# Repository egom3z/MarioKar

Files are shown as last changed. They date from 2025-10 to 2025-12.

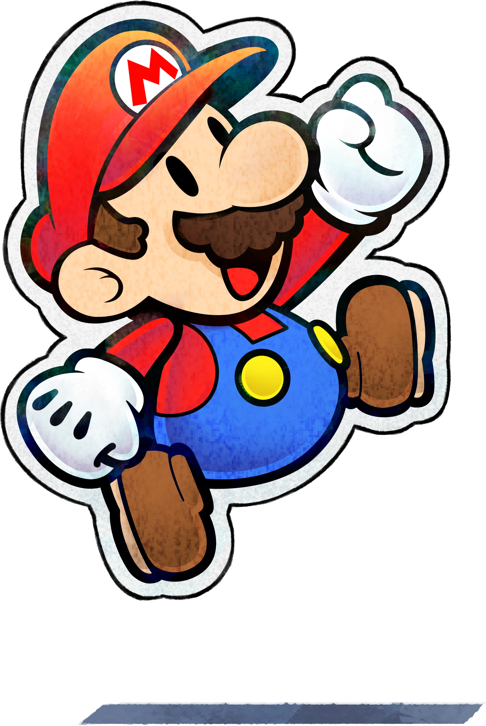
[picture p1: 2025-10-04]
Hardware/Kar_PCB_JLC/mascot.webp

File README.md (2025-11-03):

# MarioKar

## Development Setup

### Beginning Docker Container
#### **For Windows**
Before starting the docker container, the .devcontainer.json file requires that the USB device is connected the Linux distribution running on WSL 2. This will enable us to flash the ESP32 in the container. 

#### Connect USB Device
Prerequisites (can also refer to https://learn.microsoft.com/en-us/windows/wsl/connect-usb): 
* WSL is installed 
* Install USBIPD-WIN

Instructions to be done every session: 
1. Connect USB device to computer and list device in Windows Powershell in *administrator* mode: \
`usbipd list`

2. Run the command below with the bus ID of the ESP32 device: \
`usbipd bind --busid 4-4`

3. Attach the USB device: \
`usbipd attach --wsl --busid <busid>`

4. Open the **MarioKar** repo and `ctrl+shift+P` and type `Dev Containers: Rebuild and Reopen in Container`

### Build and Flash ESP32S3
If the ESP-IDF extension doesn't work when building or flashing, open a terminal within VSCode and follow the instructions below. 

1. `source /opt/esp/idf/export.sh`
2. Navigate to the project directory, and configure the target by running \
`idf.py set-target esp32s3`
3. Build the project with \
`idf.py build`
4. Flash the project to the board with \
`idf.py flash`

* After flashing, you can open the serial monitor \
`idf.py monitor`\
and close serial monitor with \
`ctrl+]`

### Alternative Setup (macOS/Linux)
```bash
# Install prerequisites
brew install cmake ninja dfu-util

# Install ESP-IDF tools
brew install espressif/idf/esp-idf-tools

# Setup ESP-IDF environment
/opt/esp/idf/install.sh
source /opt/esp/idf/export.sh

# Create and build project
cd /workspaces/MarioKar
idf.py create-project hello_world
cd hello_world
idf.py set-target esp32s3      # or esp32s3/esp32c3/etc if that's your chip
idf.py build
idf.py flash
```

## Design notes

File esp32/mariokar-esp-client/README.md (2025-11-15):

# MarioKar ESP32 BLE Client with IMU Control

ESP32-S3 BLE GATT client that reads IMU orientation and transmits servo PWM values (1000-2000 µs) to STM32WB over Bluetooth.

## Features

- ✅ **Multi-Sensor Support**: Choose between MPU6050 (I2C) or ICM-20948 (SPI)
- ✅ **Servo Mapping**: Converts roll angle (-90° to +90°) to PWM (1000-2000 µs)
- ✅ **BLE Transmission**: Sends 2-byte PWM values at 50ms intervals
- ✅ **Auto-Calibration**: Gyroscope bias calibration on startup
- ✅ **Connection Management**: Auto-scan, connect, and retry
- ✅ **Madgwick AHRS**: Sensor fusion for accurate orientation

## Supported IMU Sensors

### MPU6050 (Default - I2C)
- **Axes**: 6-axis (accelerometer + gyroscope)
- **Interface**: I2C
- **Pins (XIAO ESP32-S3)**:
  - SCL: GPIO 6
  - SDA: GPIO 5
- **Features**: 
  - ±4g accelerometer range
  - ±500°/s gyroscope range
  - No magnetometer (yaw will drift without external reference)
- **When to use**: Budget-friendly, easier wiring, sufficient for roll/pitch control

### ICM-20948 (SPI)
- **Axes**: 9-axis (accelerometer + gyroscope + magnetometer)
- **Interface**: SPI
- **Pins (XIAO ESP32-S3)**:
  - MISO: GPIO 8
  - MOSI: GPIO 9
  - SCLK: GPIO 7
  - CS: GPIO 44
- **Features**:
  - ±4g accelerometer range
  - ±500°/s gyroscope range
  - AK09916 magnetometer for absolute heading
- **When to use**: Need accurate yaw/heading, willing to pay premium

## Selecting IMU Sensor

Edit `main/sensor.h` and change the sensor type:

```c
// For MPU6050 (I2C)
#define IMU_SENSOR_TYPE     IMU_TYPE_MPU6050

// OR for ICM-20948 (SPI)
#define IMU_SENSOR_TYPE     IMU_TYPE_ICM20948
```

The build system will automatically compile only the relevant sensor driver.

## Hardware Connections

### Option 1: MPU6050 (I2C) - Default
```
MPU6050          XIAO ESP32-S3
  VCC    <-->    3.3V
  GND    <-->    GND
  SCL    <-->    GPIO 6
  SDA    <-->    GPIO 5
```

### Option 2: ICM-20948 (SPI)
```
ICM-20948        XIAO ESP32-S3
  VCC    <-->    3.3V
  GND    <-->    GND
  MISO   <-->    GPIO 8
  MOSI   <-->    GPIO 9
  SCLK   <-->    GPIO 7
  CS     <-->    GPIO 44
```

## Software Architecture

```
┌─────────────────────────────────────────────────────┐
│              app_main()                             │
│  ┌───────────────────┐  ┌──────────────────────┐  │
│  │  imu_reader_task  │  │    ble_tx_task       │  │
│  │  (100 Hz)         │  │    (20 Hz)           │  │
│  └─────────┬─────────┘  └──────────┬───────────┘  │
│            │                        │              │
│            ▼                        ▼              │
│  ┌─────────────────┐      ┌────────────────┐     │
│  │  Sensor Driver  │      │  BLE TX Buffer  │     │
│  │  (MPU/ICM)      │─────▶│  (s_latest_pwm) │     │
│  └─────────────────┘      └────────────────┘     │
│            │                        │              │
│            ▼                        ▼              │
│  ┌─────────────────┐      ┌────────────────┐     │
│  │ Madgwick Filter │      │  GATT Client   │     │
│  │ (6/9-DOF AHRS)  │      │                │     │
│  └─────────────────┘      └────────┬───────┘     │
│            │                        │              │
│            ▼                        ▼              │
│  ┌─────────────────┐      ┌────────────────┐     │
│  │ Euler Angles    │      │   STM32WB      │     │
│  │ (Roll/Pitch/Yaw)│      │   (BLE Server) │     │
│  └─────────────────┘      └────────────────┘     │
└─────────────────────────────────────────────────────┘
```

## Building and Flashing

### Prerequisites
```bash
# Install ESP-IDF v5.x
cd /opt/esp/idf
./install.sh
source export.sh
```

### Build
```bash
cd esp32/mariokar-esp-client
idf.py set-target esp32s3
idf.py build
```

### Flash
```bash
idf.py flash monitor
```

### Expected Output
```
I (1234) MPU6050: Initializing MPU6050 IMU
I (1245) MPU6050: MPU6050 initialized successfully (I2C mode)
I (1250) MPU6050: Calibrating gyroscope... keep device stationary!
I (1255) MPU6050: Progress: 0%
...
I (3456) MPU6050: Calibration complete (1000 samples)
I (3460) MPU6050: Gyro offsets: X=-0.234 Y=0.123 Z=-0.056 deg/s
I (3465) GATTC_CLEAN: IMU ready, starting orientation tracking
I (3470) GATTC_CLEAN: BLE TX task started (interval 50 ms)
I (4567) GATTC_CLEAN: Found target device MyCST
I (5678) GATTC_CLEAN: P2P Service found: start=0x000c end=0x0010
I (5890) GATTC_CLEAN: LED value handle 0x000d
I (6123) GATTC_CLEAN: SWITCH decl handle 0x000f
I (6234) GATTC_CLEAN: Notifications enabled.
I (6345) GATTC_CLEAN: BLE TX: PWM=1500 µs [0xDC 0x05]
I (7456) GATTC_CLEAN: IMU: Roll=-15.3° -> PWM=1415 µs
```

## Calibration

**Important**: Keep the device **completely stationary** during the ~2 second gyroscope calibration on startup. This measures and removes gyroscope bias for accurate orientation tracking.

## Steering Control Mapping

The system uses **ROLL** angle for steering:

| Roll Angle | Servo PWM | Steering Direction |
|---|---|---|
| -90° | 1000 µs | Full Left |
| -45° | 1250 µs | Half Left |
| 0° | 1500 µs | Center/Straight |
| +45° | 1750 µs | Half Right |
| +90° | 2000 µs | Full Right |

## Code Structure

```
main/
├── main.c              # BLE client, IMU reader, TX tasks
├── sensor.h            # Common IMU API & sensor selection
├── sensor.c            # ICM-20948 driver (SPI, 9-axis)
├── sensor_mpu6050.c    # MPU6050 driver (I2C, 6-axis)
├── idf_component.yml   # MPU6050 component dependency
└── CMakeLists.txt      # Build configuration
```

## Sensor Fusion Details

Both sensors use the **Madgwick AHRS algorithm** for sensor fusion:

### MPU6050 (6-DOF Mode)
- Fuses accelerometer + gyroscope data
- No magnetometer → **yaw will drift** over time
- Excellent for roll and pitch (used for steering)
- Sample rate: 100 Hz
- Filter beta: 0.1 (tunable for response vs smoothness)

### ICM-20948 (9-DOF Mode)
- Fuses accelerometer + gyroscope + magnetometer
- Magnetometer provides absolute heading reference
- Yaw is stable and doesn't drift
- Sample rate: 100 Hz
- Filter beta: 0.1

## Troubleshooting

### IMU not detected
**MPU6050:**
- Check I2C connections (SCL on GPIO 6, SDA on GPIO 5)
- Verify 3.3V power supply
- Try adding external 4.7kΩ pull-up resistors on SCL/SDA

**ICM-20948:**
- Check SPI connections (see pinout above)
- Verify CS line is connected to GPIO 44
- Ensure 3.3V power (not 5V)

### Orientation drifts
- Ensure device was **stationary** during calibration
- For MPU6050: Yaw drift is normal (no magnetometer)
- Recalibrate by restarting the device
- Check for magnetic interference if using ICM-20948

### BLE connection fails
- Verify STM32WB is advertising as "MyCST"
- Check that P2P service UUID matches
- Monitor with `idf.py monitor` for connection logs
- Try power cycling both devices

### Roll angle reversed
- Swap sign in `angle_to_servo_pwm()` function in `main.c`
- Or physically mount IMU rotated 180°

## Customization

### Change steering axis
In `main.c`, line ~412:
```c
// Use PITCH instead of ROLL
s_latest_pwm = angle_to_servo_pwm(orientation.pitch);

// Or use YAW (only stable with ICM-20948)
s_latest_pwm = angle_to_servo_pwm(orientation.yaw);
```

### Adjust transmission rate
In `main.c`, line ~34:
```c
#define BLE_TX_INTERVAL_MS      50  // Change to 20 for 50Hz, 100 for 10Hz
```

### Tune sensor fusion
In `sensor_mpu6050.c` or `sensor.c`, adjust filter parameters:
```c
madgwick_init(&g_filter, 100.0f, 0.1f);
//                        ^       ^
//                        |       beta (filter gain)
//                        sample rate (Hz)
```

## Performance Metrics

| Metric | MPU6050  | ICM-20948 |
|---|---|---|
| Update Rate | 100 Hz | 100 Hz |
| BLE TX Rate | 20 Hz | 20 Hz |
| Roll/Pitch Accuracy | ±2° | ±2° |
| Yaw Accuracy | Drifts | ±5° |
| Calibration Time | ~2 sec | ~2 sec |
| Latency (IMU→BLE) | ~60 ms | ~60 ms |

## License

See project root LICENSE file.

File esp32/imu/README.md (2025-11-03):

# ICM-20948 IMU Driver

Clean, production-quality driver for the ICM-20948 9-axis IMU with SPI interface.

## Features

- ✅ **SPI Communication** - 4 MHz SPI interface with proper register banking
- ✅ **9-Axis Fusion** - Accelerometer, gyroscope, and magnetometer
- ✅ **Madgwick AHRS** - Quaternion-based sensor fusion for accurate orientation
- ✅ **Auto Calibration** - Gyroscope bias calibration on startup
- ✅ **I2C Master Mode** - Automatic magnetometer reading via I2C passthrough
- ✅ **Clean API** - Simple, well-documented interface

## Hardware Configuration

**XIAO ESP32S3 Pin Mapping:**
- MISO: GPIO 8
- MOSI: GPIO 9
- SCLK: GPIO 7
- CS: GPIO 44

## Sensor Configuration

- **Gyroscope**: ±500 dps, DLPF enabled (51.2 Hz bandwidth)
- **Accelerometer**: ±4g, DLPF enabled (50.4 Hz bandwidth)
- **Magnetometer**: Continuous 100 Hz mode via I2C master
- **Update Rate**: 100 Hz (10ms loop)

## API Usage

### Initialization

```c
#include "sensor.h"

void app_main(void) {
    if (imu_init() == ESP_OK) {
        ESP_LOGI("MAIN", "IMU ready");
        xTaskCreate(imu_task, "imu_task", 4096, NULL, 5, NULL);
    }
}
```

### Reading Sensors

```c
imu_data_t data;
if (imu_read_sensors(&data) == ESP_OK) {
    // data.accel_x, accel_y, accel_z (in g)
    // data.gyro_x, gyro_y, gyro_z (in deg/s)
    // data.mag_x, mag_y, mag_z (in uT)
    // data.mag_valid (magnetometer data ready flag)
}
```

### Getting Orientation

```c
imu_orientation_t orientation;
imu_get_orientation(&orientation);
// orientation.roll, pitch, yaw (in degrees)
```

### Manual Sensor Fusion

```c
float dt = 0.01f;  // 10ms
imu_update_fusion(&data, dt);
```

## Expected Behavior

### At Rest (Device Stationary)
- **Accelerometer magnitude**: ~1.0g (±0.1)
- **Gyroscope**: Near 0 deg/s after calibration
- **Roll/Pitch**: Near 0° if device is level
- **Yaw**: Arbitrary value aligned with magnetic north

### During Motion
- **Roll**: ±180° rotation around X-axis
- **Pitch**: ±90° rotation around Y-axis (gimbal lock at ±90°)
- **Yaw**: ±180° rotation around Z-axis (heading)

## Implementation Details

### Register Banking
The ICM-20948 uses register banks (0-3). The driver automatically tracks and switches banks as needed.

### Magnetometer Access
The AK09916 magnetometer is accessed via I2C master mode in the ICM-20948. The driver sets up continuous reading so magnetometer data appears in the external sensor data registers.

### Madgwick Filter
- Beta gain: 0.1 (tunable for responsiveness vs. stability)
- Uses fast inverse square root for efficiency
- Full 9-axis fusion with magnetometer correction

### Calibration
Gyroscope bias is measured on startup (1000 samples while stationary). The bias is automatically subtracted from all gyro readings.

## Build and Flash

```bash
cd /Users/enriquegomez/CMU/Fall-2025/18-500/MarioKar/esp32/imu
idf.py build
idf.py flash monitor
```

## Troubleshooting

### "Magnetometer not detected"
- Check I2C connections on the ICM-20948 board
- Verify magnetometer is powered
- Some breakout boards have magnetometer on a separate chip

### "Accel magnitude outside range"
- Check sensor orientation
- Verify ACCEL_CONFIG register (should be 0x13 for ±4g)
- Ensure device is stable during initialization

### Roll/Pitch/Yaw drifting
- Ensure gyroscope calibration completes successfully
- Keep device stationary during calibration
- Check magnetometer readings (mag_valid should be true)
- Increase calibration samples if needed

### SPI communication fails
- Verify GPIO pin assignments match your board
- Check SPI mode (should be mode 0)
- Ensure CS line is correctly connected

## Code Structure

```
sensor.h        - Public API and data structures
sensor.c        - Complete driver implementation
  ├── SPI layer (select_bank, read/write registers)
  ├── Magnetometer I2C master functions
  ├── Madgwick AHRS filter
  ├── Sensor reading functions
  └── Main IMU task with calibration
imu.c          - Application entry point
```

## Performance

- **CPU Usage**: ~2% on ESP32S3 @ 240MHz
- **RAM Usage**: <1KB static, ~2KB stack per task
- **Update Rate**: 100 Hz
- **Latency**: <2ms from sensor read to orientation output

## License

Part of MarioKar project - CMU 18-500 Fall 2025

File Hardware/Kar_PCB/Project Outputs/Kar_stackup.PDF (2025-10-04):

# Board Stack Report

Stack Up | Layer Stack
Layer | Board Layer Stack | Name | Material | Thickness | Constant

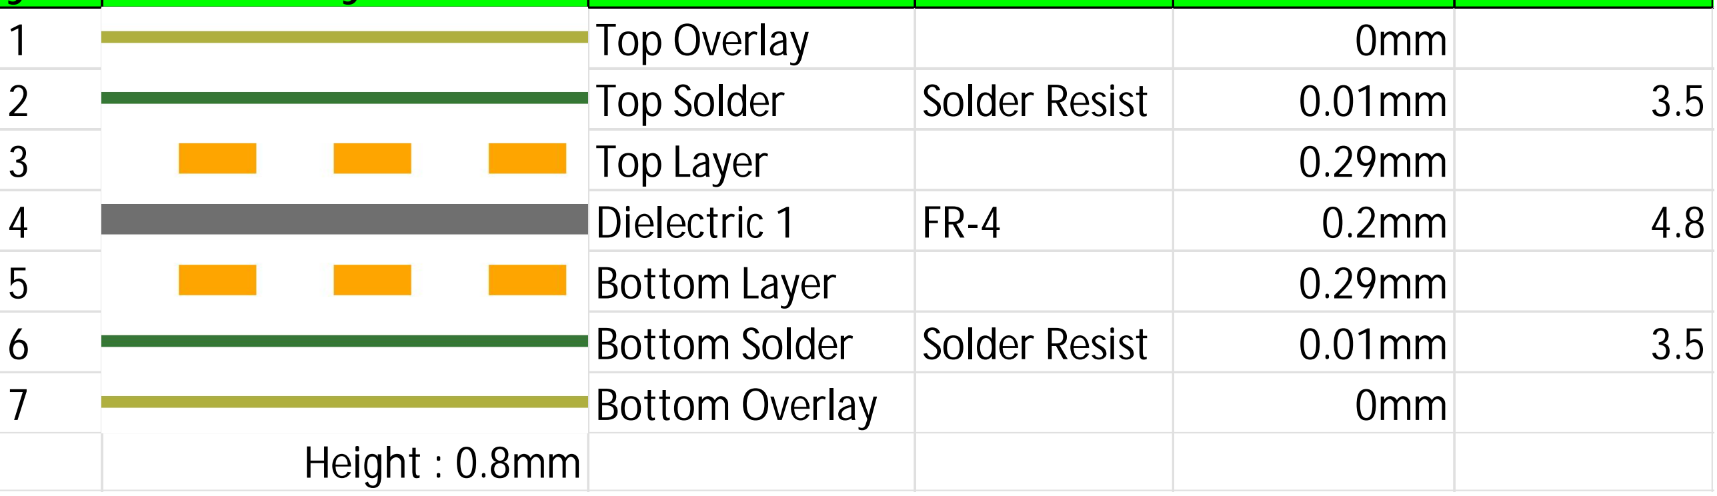
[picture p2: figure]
Top Overlay; Top Solder; Solder Resist; Top Layer; Dielectric 1; Bottom Layer; Bottom Solder; Bottom Overlay; Height : 0.8mm

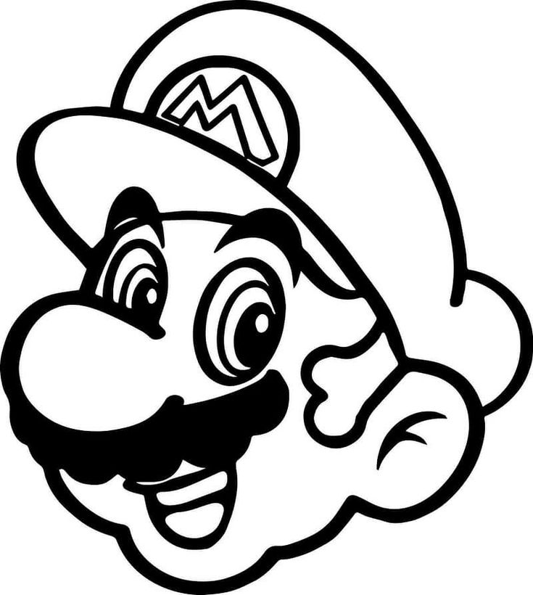
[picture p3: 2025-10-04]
Hardware/Kar_PCB_JLC/mascot.jpg

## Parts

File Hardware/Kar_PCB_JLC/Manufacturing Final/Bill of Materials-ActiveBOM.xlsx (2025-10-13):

Line # | Name | Manufacturer Part Number 1 | Designator | Quantity | Manufacturer 1 | Description | Type | Package
1 | 1048P | 1048P | BT1, BT2 | 2 | Keystone Electronics | SMT Polarized Holder for Dual 18650 Batteries | SMD | None
2 | C2012X5R1H106K125AC | C2012X5R1H106K125AC | C1, C9, C28 | 3 | TDK | C0805 MLCC 10uF 50V 10% X5R | SMD | 0805
3 | KAM21BR71H104JM | KAM21BR71H104JM | C2, C7, C8, C10, C24, C25 | 6 | Kyocera AVX | C0805 MLCC 0.1uF 50V 5% X7R | SMD | 0805
4 | C2012X5R1V226M125AC | C2012X5R1V226M125AC | C3, C4 | 2 | TDK | C0805 MLCC 22uF 35V 20% X5R | SMD | 0805
5 | T58W0476M8R2C0500 | T58W0476M8R2C0500 | C5 | 1 | Vishay | C0805 TANT POLY 47uF 8.2V 20% | SMD | 0805
6 | GCM21BR71H474KA55K | GCM21BR71H474KA55K | C6 | 1 | Murata Electronics | C0805 MLCC 0.47uF 50V 10% X7R | SMD | 0805
7 | C2012X7R1H225K125AE | C2012X7R1H225K125AE | C26 | 1 | TDK | C0805 MLCC 22uF 50V 10% X7R | SMD | 0805
8 | KGM21AR51H105KU | KGM21AR51H105KU | C27 | 1 | Kyocera AVX | C0805 MLCC 1uF 50V 10% X5R | SMD | 0805
9 | WL-SMCW_0603 | 150060GS75000 | D1 | 1 | Wurth Elektronik | LED GREEN CLEAR 0603 SMD | SMD | 0603
10 | Fiducial |  | F1, F2, F3, F4 | 4 |  |  | SMD
11 | DNP | DNP | J1 | 1 | DNP | DNP | DNP | DNP
12 | DNP | DNP | J2 | 1 | DNP | DNP | DNP | DNP
13 | DNP | DNP | J3, J4 | 2 | DNP | DNP | DNP | DNP
14 | MPZ2012S601AT000 | MPZ2012S601AT000 | L1, L2 | 2 | TDK | FERRITE BEAD 600 OHM 0805 1LN | SMD | 0805
15 | ICM-42670-P | ICM-42670-P | MT1 | 1 | TDK InvenSense | IMU ACCEL/GYRO/TEMP I2C/SPI | SMD | 14-VFLGA
16 | TPSM843321RCJR | TPSM843321RCJR | PS1 | 1 | Texas Instruments | 3.8V TO 18V INPUT, 3A, 200KHZ TO | SMD | 9-PowerFQFN Module
17 | RC0805FR-0773K2L | RC0805FR-0773K2L | R1 | 1 | YAGEO | RES 0805 73.2k 1% 1/8W | SMD | 0805
18 | RC0805FR-0710KL | RC0805FR-0710KL | R2, R4, R13, R14 | 4 | YAGEO | RES 0805 10k 1% 1/8W | SMD | 0805
19 | RC0805FR-0718KL | RC0805FR-0718KL | R3, R5 | 2 | YAGEO | RES 0805 18k 1% 1/8W | SMD | 0805
20 | RC0805FR-0722KL | RC0805FR-0722KL | R6 | 1 | YAGEO | RES 0805 22k 1% 1/8W | SMD | 0805
21 | RC0805JR-07100RL | RC0805JR-07100RL | R7, R10, R11, R12, R15, R16, R17 | 7 | YAGEO | RES 0805 100 5% 1/8W | SMD | 0805
22 | RC0805JR-074K7L | RC0805JR-074K7L | R8, R9, R18 | 3 | YAGEO | RES 0805 4.7k 5% 1/8W | SMD | 0805
23 | DNP | DNP | S1 | 1 | DNP | DNP | DNP | DNP
24 | DNP | DNP | SW1 | 1 | DNP | DNP | DNP | DNP
25 | LM3940ISX-3.3/NOPB | LM3940ISX-3.3/NOPB | U1 | 1 | Texas Instruments | IC REG LINEAR 3.3V 1A TO263 | SMD | TO-263
26 | DRV8242SQRHLRQ1 | DRV8242SQRHLRQ1 | U2 | 1 | Texas Instruments | Automotive, 40-V 6-A H-bridge driver with integrated current sensing and feedback 20-VQFN -40 to 125 | SMD | 20-VFQFN
27 | SN74LV1T34DBVR | SN74LV1T34DBVR | U3 | 1 | Texas Instruments | IC BUFF NON-INVERT 5.5V SOT-23-5 | SMD | SOT-23-5
28 | DNP | DNP | U4 | 1 | DNP | DNP | DNP | DNP
29 | MMC5983MA | MMC5983MA | U5 | 1 | Memsic Inc. | 3-AXIS MAGNETIC SENSOR | DNP | 14-VFLGA

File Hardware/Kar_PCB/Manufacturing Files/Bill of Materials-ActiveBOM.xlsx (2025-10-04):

Line # | Name | Manufacturer Part Number 1 | Designator | Quantity | Manufacturer 1 | Description | Type | Package
1 | MLPF-WB55-01E3 | MLPF-WB55-01E3 | AE1 | 1 | STMicroelectronics | 2.4 GHz Matched filter companion chip for STM32WB55Cx and STM32WB55Rx | SMT | 6-SMD
2 | W3078 | W3078 | B1 | 1 | Pulse Electronics | Antennas CERAMIC W3078 GC380H N | SMT
3 | 1048P | 1048P | BT1, BT2 | 2 | Keystone Electronics | SMT Polarized Holder for Dual 18650 Batteries | SMT
4 | C2012X5R1H106K125AC | C2012X5R1H106K125AC | C1, C9, C28 | 3 | TDK | MLCC 0805 10u 10% 50V X5R | SMT | 0805
5 | KAM21BR71H104JM | KAM21BR71H104JM | C2, C7, C8, C10, C11, C12, C13, C17, C19, C22, C24, C25 | 12 | KYOCERA AVX | MLCC 0805 0.1u 5% 50V X7R | SMT | 0805
6 | C2012X5R1V226M125AC | C2012X5R1V226M125AC | C3, C4 | 2 | TDK | MLCC 0805 22u 20% 35V X5R | SMT | 0805
7 | C2012X5R1A336M125AC | C2012X5R1A336M125AC | C5 | 1 | TDK | MLCC 0805 33u 20% 10V X5R | SMT | 0805
8 | GCM21BR71H474KA55K | GCM21BR71H474KA55K | C6 | 1 | Murata Electronics | MLCC 0805 0.47u 10% 50V X7R | SMT | 0805
9 | C2012X5R1H475M125AB | C2012X5R1H475M125AB | C14, C21, C23 | 3 | TDK | MLCC 0805 4.7u 20% 50V X5R | SMT | 0805
10 | KAM21BR71H103KT | KAM21BR71H103KT | C15 | 1 | KYOCERA AVX | MLCC 0805 0.01u 10% 50V X7R | SMT | 0805
11 | KGM21AR51H105KU | KGM21AR51H105KU | C16, C18, C20, C27 | 4 | KYOCERA AVX | MLCC 0805 1u 10% 50V X5R | SMT | 0805
12 | C2012X7R1H225K125AE | C2012X7R1H225K125AE | C26 | 1 | TDK | MLCC 0805 2.2u 10% 50V X7R | SMT | 0805
13 | WL-SMCW_0603 | 150060GS75000 | D1 | 1 | Wurth | 0603, Green Typ.(@20mA): 520nm, 430mcd, 3.2V, 140Â° InGaN | SMT | 0603
14 | DNP | DNP | J1 | 1 | DNP | DNP | DNP | DNP
15 | DNP | DNP | J2 | 1 | DNP | DNP | DNP | DNP
16 | DNP | DNP | J3 | 1 | DNP | DNP | DNP | DNP
17 | LQM21FN100M80L | LQM21FN100M80L | L1 | 1 | Murata Electronics | FIXED IND 10UH 100MA 390MOHM SMD | SMT | 0805
18 | ICM-42670-P | ICM-42670-P | MT1 | 1 | TDK InvenSense | IMU ACCEL/GYRO/TEMP I2C/SPI | SMT | 14-VFLGA
19 | TPSM843321RCJR | TPSM843321RCJR | PS1 | 1 | Texas Instruments | 3.8V TO 18V INPUT, 3A, 200KHZ TO | SMT | 9-PowerFQFN
20 | RC0805FR-0773K2L | RC0805FR-0773K2L | R1 | 1 | YAGEO | RES 0805 73.2k 1% 1/8W | SMT | 0805
21 | RC0805FR-0710KL | RC0805FR-0710KL | R2, R4, R13, R14 | 4 | YAGEO | RES 0805 10k 1% 1/8W | SMT | 0805
22 | RC0805FR-0718KL | RC0805FR-0718KL | R3, R5 | 2 | YAGEO | RES 0805 18k 1% 1/8W | SMT | 0805
23 | RC0805FR-0722KL | RC0805FR-0722KL | R6 | 1 | YAGEO | RES 0805 22k 1% 1/8W | SMT | 0805
24 | RC0805JR-07100RL | RC0805JR-07100RL | R7, R10, R11, R12, R15, R16, R17 | 7 | YAGEO | RES 0805 100 5% 1/8W | SMT | 0805
25 | RC0805JR-074K7L | RC0805JR-074K7L | R8, R9 | 2 | YAGEO | RES 0805 4.7k 5% 1/8W | SMT | 0805
26 | DNP | DNP | S1 | 1 | DNP | DNP | DNP | DNP
27 | DNP | DNP | S2 | 1 | DNP | DNP | DNP | DNP
28 | LM3940ISX-3.3/NOPB | LM3940ISX-3.3/NOPB | U1 | 1 | Texas Instruments | IC REG LINEAR 3.3V 1A TO263 | SMT | DDPAK/TO-263
29 | DRV8242SQRHLRQ1 | DRV8242SQRHLRQ1 | U2 | 1 | Texas Instruments | Automotive, 40-V 6-A H-bridge driver with integrated current sensing and feedback 20-VQFN -40 to 125 | SMT | 20-VFQFN
30 | SN74LV1T34DBVR | SN74LV1T34DBVR | U3 | 1 | Texas Instruments | Single Power Supply BUFFER Logic Level Shifter (no enable) | SMT | SOT-23-5
31 | STM32WB55RGV6TR | STM32WB55RGV6TR | U4 | 1 | STMicroelectronics | Ultra-low-power dual core Arm Cortex-M4 MCU 64 MHz, Cortex-M0+ 32 MHz with 1 Mbyte of Flash memory, Bluetooth LE 5.4, 802.15.4, Zigbee, Thread, Matter, USB, LCD, AES-256 | SMT | 68-VFQFN
32 | MMC5983MA | MMC5983MA | U5 | 1 | Memsic Inc. | Magnetoresistive Sensor X, Y, Z Axis 16-LGA (3x3) | SMT | 16-VFLGA
33 | CX2016DB32000D0WZRC1 | CX2016DB32000D0WZRC1 | X1 | 1 | KYOCERA AVX | 32 MHz +/-25ppm Crystal 8pF 60 Ohms 4-SMD, No Lead | SMT | 4-SMD

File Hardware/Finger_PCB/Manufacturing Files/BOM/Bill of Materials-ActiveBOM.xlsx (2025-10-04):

Line # | Name | Manufacturer Part Number 1 | Designator | Quantity | Manufacturer 1 | Description | Type | Package
1 | KAM21BR71H104JM | KAM21BR71H104JM | C1, C2 | 2 | Kyocera | MLCC 0805 0.1u 5% 50V X7R | SMT | 0805
2 | C2012X7R1H225K125AE | C2012X7R1H225K125AE | C3 | 1 | TDK | MLCC 0805 2.2u 10% 50V X7R | SMT | 0805
3 | WL-SMCW_0603 | 150060YS75000 | D1 | 1 | Wurth | 0603, Yellow Typ.(@20mA): 590nm, 120mcd, 2.0V, 140Â° AlInGaP | SMT | 0603
4 | SM06B-GHS-TB | SM06B-GHS-TB | J1 | 1 | JST | CONN HEADER SMD R/A 6POS 1.25MM | SMT
5 | ICM-42670-P | ICM-42670-P | MT1 | 1 | TDK InvenSense | IMU ACCEL/GYRO/TEMP I2C/SPI | SMT | 14-VFLGA
6 | RC0805JR-07100RL | RC0805JR-07100RL | R1 | 1 | Yageo | RES 0805 100 5% 1/8W | SMT | 0805
7 | RT0603BRD0750RL | RT0603BRD0750RL | R2 | 1 | Yageo | RES 0603 10 0.1% 1/10W | SMT | 0603

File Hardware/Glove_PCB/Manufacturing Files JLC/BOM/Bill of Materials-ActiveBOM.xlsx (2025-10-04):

Line # | Name | Manufacturer Part Number 1 | Designator | Quantity | Manufacturer 1 | Description | Type | Package
1 | KAM21BR71H104JM | KAM21BR71H104JM | C1, C2 | 2 | Kyocera Avx | MLCC 0805 0.1u 5% 50V X7R | SMT | 0805
2 | C2012X7R1H225K125AE | C2012X7R1H225K125AE | C3 | 1 | TDK | MLCC 0805 2.2u 10% 50V X7R | SMT | 0805
3 | GCM21BR71H474KA55K | GCM21BR71H474KA55K | C4 | 1 | Murata | MLCC 0805 0.47u 10% 50V X7R | SMT | 0805
4 | C2012X5R1A336M125AC | C2012X5R1A336M125AC | C5 | 1 | TDK | MLCC 0805 33u 20% 10V X5R | SMT | 0805
5 | WL-SMCW_0603_Y | 150060YS75000 | D1, D4 | 2 | Wurth | 0603, Yellow Typ.(@20mA): 590nm, 120mcd, 2.0V, 140Â° AlInGaP | SMT | 0603
6 | WL-SMCW_0603_R | 150060RS75000 | D2, D3 | 2 | Wurth | 0603, Super Red Typ.(@20mA): 630nm, 60mcd, 1.9V, 140Â° AlInGaP | SMT | 0603
7 | SM06B-GHS-TB | SM06B-GHS-TB | J1 | 1 | JST | CONN HEADER SMD R/A 6POS 1.25MM | Type
8 | DNP | DNP | J2 | 1 | DNP | DNP | DNP | DNP
9 | ICM-42670-P | ICM-42670-P | MT1 | 1 | TDK InvenSense | IMU ACCEL/GYRO/TEMP I2C/SPI | SMT | 14-VFLGA
10 | RC0805JR-07100RL | RC0805JR-07100RL | R1, R5, R7 | 3 | Yageo | RES 0805 100 5% 1/8W | SMT | 0805
11 | RC0805JR-074K7L | RC0805JR-074K7L | R2, R3, R4, R6, R8, R9 | 6 | Yageo | RES 0805 4.7k 5% 1/8W | SMT | 0805
12 | RT0603BRD0750RL | RT0603BRD0750RL | R10, R11, R12, R13 | 4 | Yageo | RES 0603 50 0.1% 1/10W | SMT | 0603
13 | SLW-913535-2A-SMT | SLW-913535-2A-SMT | SW1 | 1 | Same Sky | SWITCH SLIDE DPDT 0.1A 12V | SMT
14 | DNP | DNP | U1 | 1 | DNP | DNP | DNP | DNP
15 | DNP | DNP | U2 | 1 | DNP | DNP | DNP | DNP
16 | LM3940ISX-3.3/NOPB | LM3940ISX-3.3/NOPB | U3 | 1 | Texas Instruments | IC REG LINEAR 3.3V 1A TO263 | LM3940IS-3.3 | DDPAK/TO-263

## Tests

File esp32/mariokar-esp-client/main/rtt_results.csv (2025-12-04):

Distance (ft) | RTT1 | RTT2 | RTT3 | RTT4 | RTT5 | RTT6 | RTT7 | RTT8 | RTT9 | RTT10 | RTT11 | RTT12
0.0 | 56.792 | 56.791 | 56.792 | 56.786 | 56.787 | 56.787 | 56.793 | 56.787 | 56.791 | 56.787 | 56.785 | 56.78
12.0 | 56.79 | 56.795 | 56.791 | 56.79 | 56.784 | 56.792 | 56.79 | 56.792 | 56.789 | 56.787 | 56.796
24.0 | 81.788 | 56.692 | 56.787 | 56.688 | 56.791 | 56.787 | 56.784 | 56.695 | 56.793 | 56.707 | 56.0
36.0 | 56.79 | 56.693 | 56.791 | 56.792 | 56.79 | 56.793 | 56.688 | 56.792 | 56.702 | 56.695
48.0 | 56.786 | 56.7 | 56.788 | 56.794 | 56.79 | 56.775 | 56.785 | 56.765 | 81.79 | 81.798
60.0 | 81.705 | 56.689 | 56.794 | 81.798 | 81.783 | 81.701 | 56.79 | 81.305 | 56.786 | 56.795
72.0 | 106.801 | 81.707 | 106.705 | 56.786 | 157.038 | 56.708 | 56.707 | 81.404 | 106.798 | 56.796
84.0

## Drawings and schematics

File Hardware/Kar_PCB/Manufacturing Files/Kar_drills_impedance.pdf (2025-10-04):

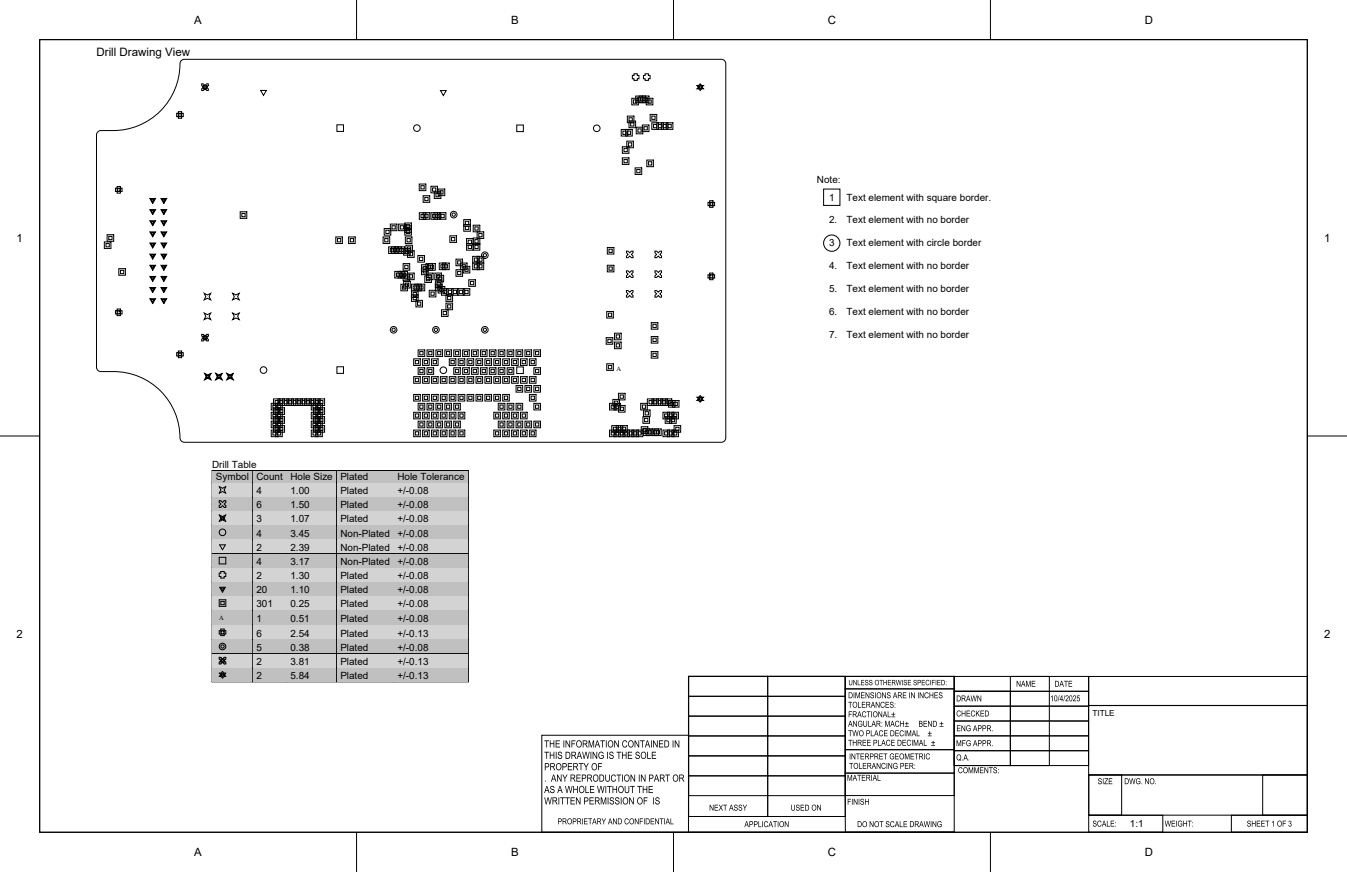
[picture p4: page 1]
Drill Table; TITLE

Drill Drawing View

Note:
1 Text element with square border.

2. Text element with no border

3 Text element with circle border

4. Text element with no border

5. Text element with no border

6. Text element with no border

7. Text element with no border

Symbol | Count | Hole Size | Plated | Hole Tolerance

4 | 1.00 | Plated | +/-0.08
6 | 1.50 | Plated | +/-0.08
3 | 1.07 | Plated | +/-0.08
4 | 3.45 | Non-Plated | +/-0.08
2 | 2.39 | Non-Plated | +/-0.08
4 | 3.17 | Non-Plated | +/-0.08
2 | 1.30 | Plated | +/-0.08
20 | 1.10 | Plated | +/-0.08
301 | 0.25 | Plated | +/-0.08

A | | | 1 | 0.51 | Plated | +/-0.08

6 | 2.54 | Plated | +/-0.13
5 | 0.38 | Plated | +/-0.08
2 | 3.81 | Plated | +/-0.13
2 | 5.84 | Plated | +/-0.13

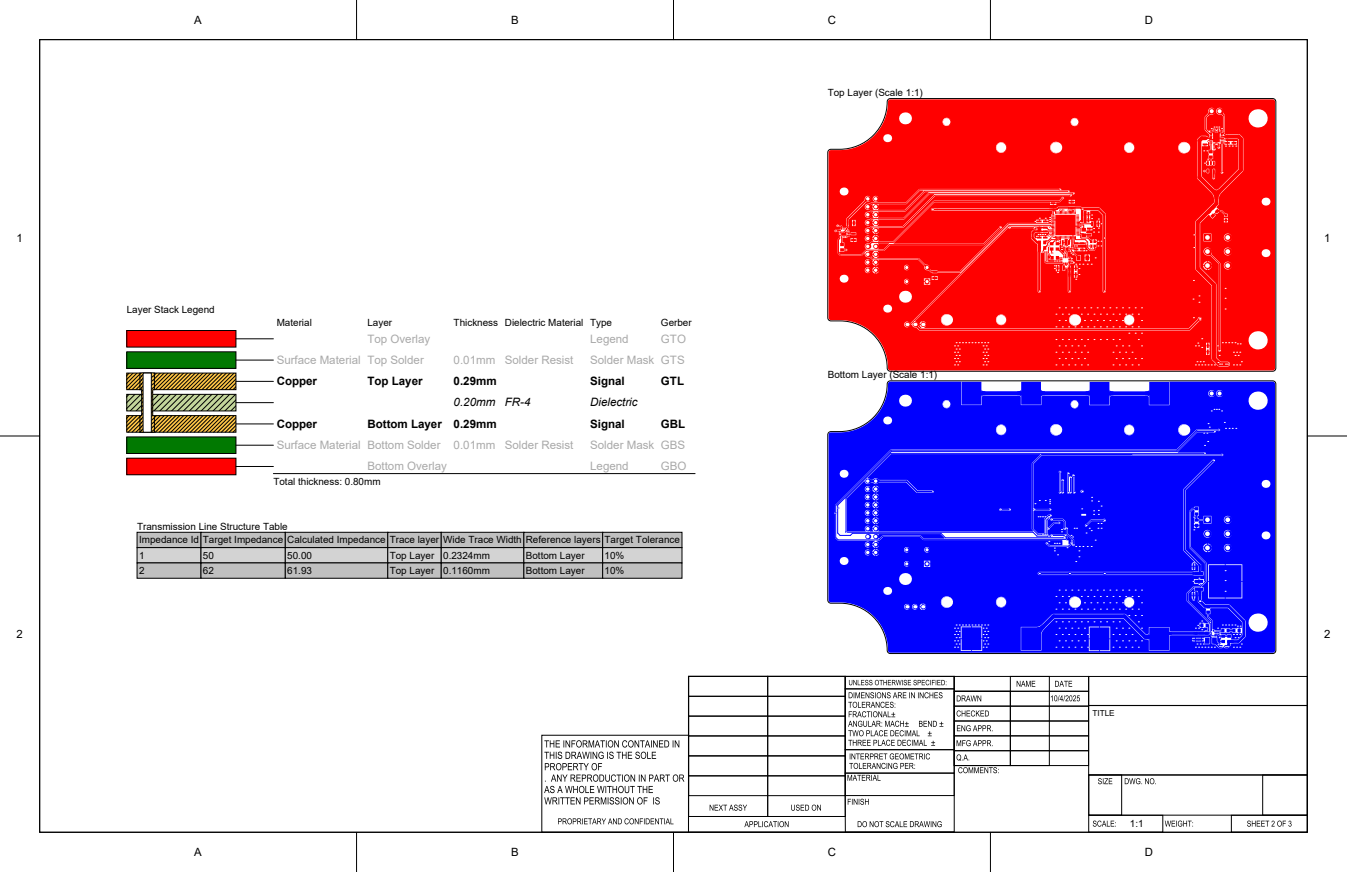
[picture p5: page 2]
Material; Layer; Thickness Dielectric Material Type; Gerber; Top Overlay; Legend; GTO; Surface Material Top Solder; 0.01mm Solder Resist; Solder Mask GTS; Copper; Top Layer; Signal; GTL; Dielectric; Bottom Layer 0.29mm; GBL; Surface Material Bottom Solder 0.01mm Solder Resist; Solder Mask GBS; Bottom Overlay; GBO; Total thickness: 0.80mm; TITLE; Target Impedance 50 62; Calculated Impedance 50.00 61.93; Trace layer Top Layer Top Layer; Wide Trace Width 0.2324mm 0.1160mm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

Top Layer (Scale 1:1)

Layer Stack Legend

Bottom Layer (Scale 1:1)

Transmission Line Structure Table
Impedance Id

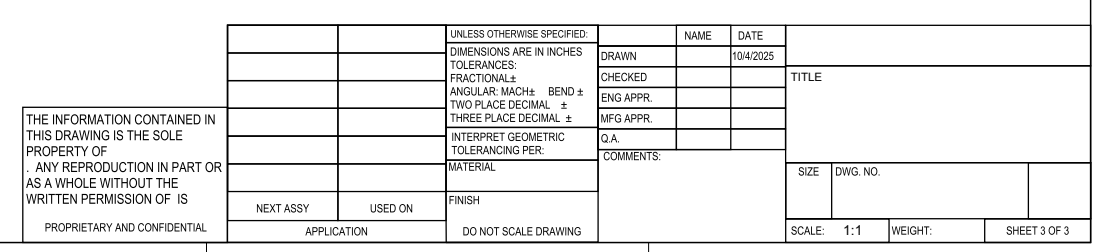
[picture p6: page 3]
TITLE

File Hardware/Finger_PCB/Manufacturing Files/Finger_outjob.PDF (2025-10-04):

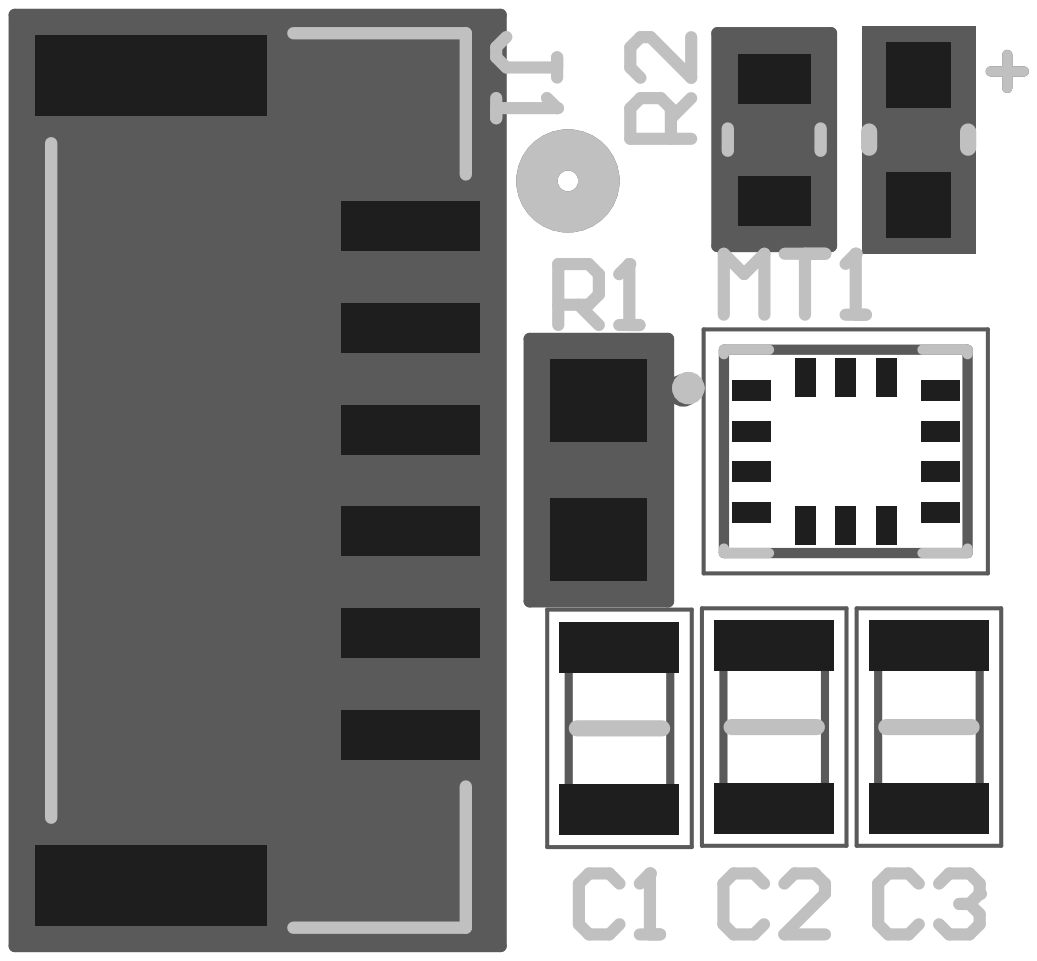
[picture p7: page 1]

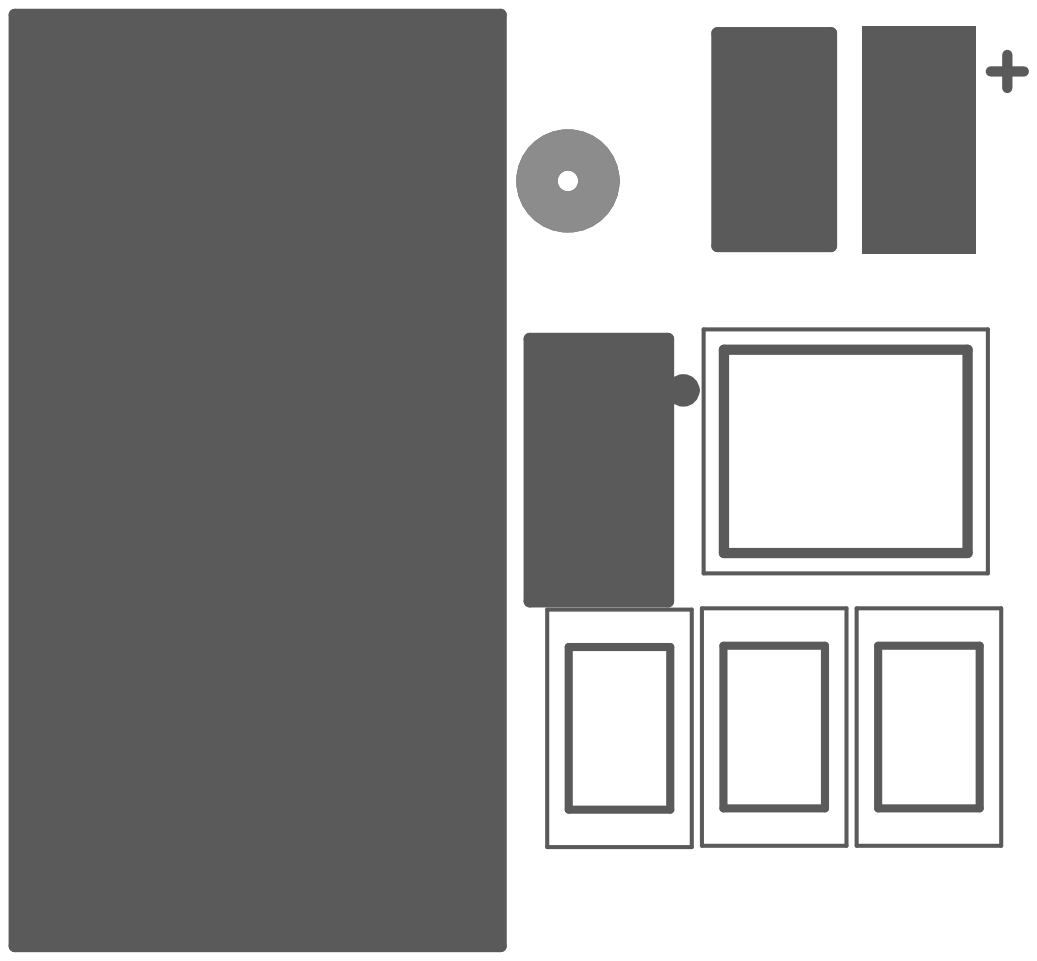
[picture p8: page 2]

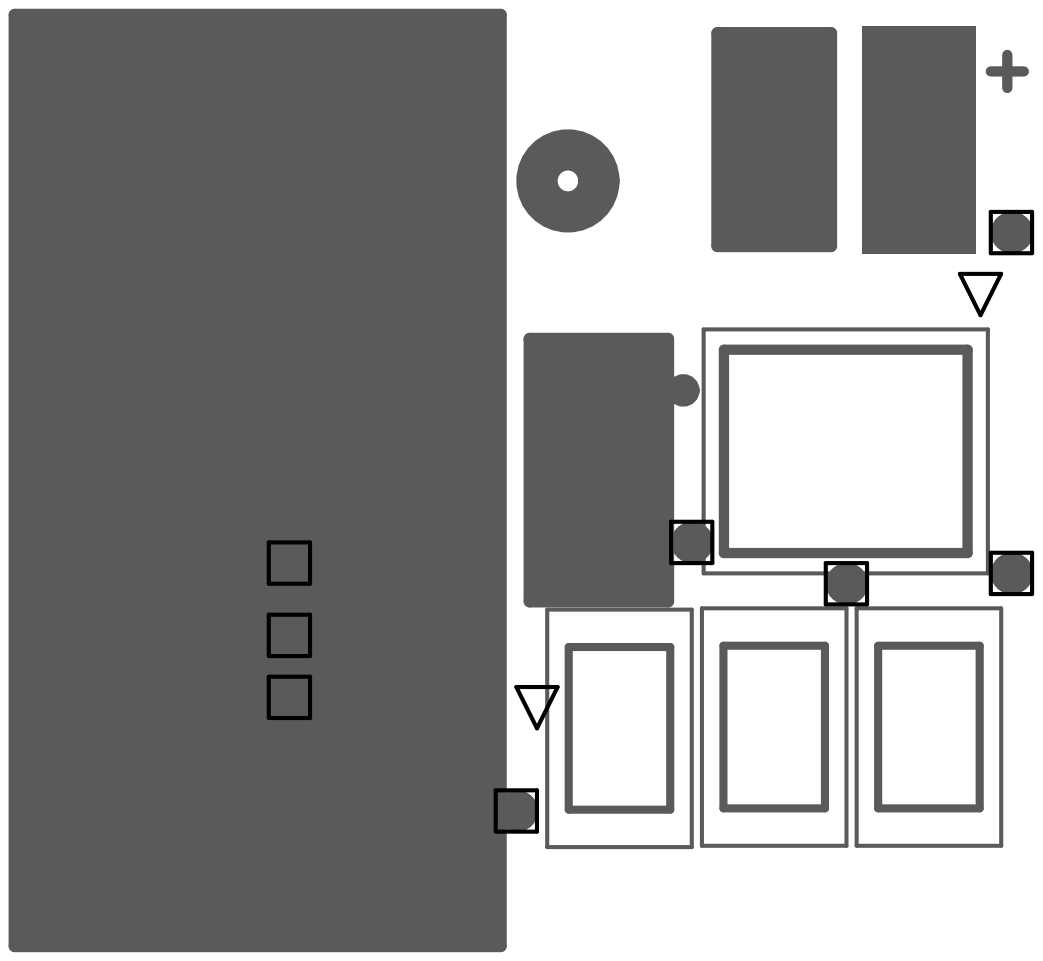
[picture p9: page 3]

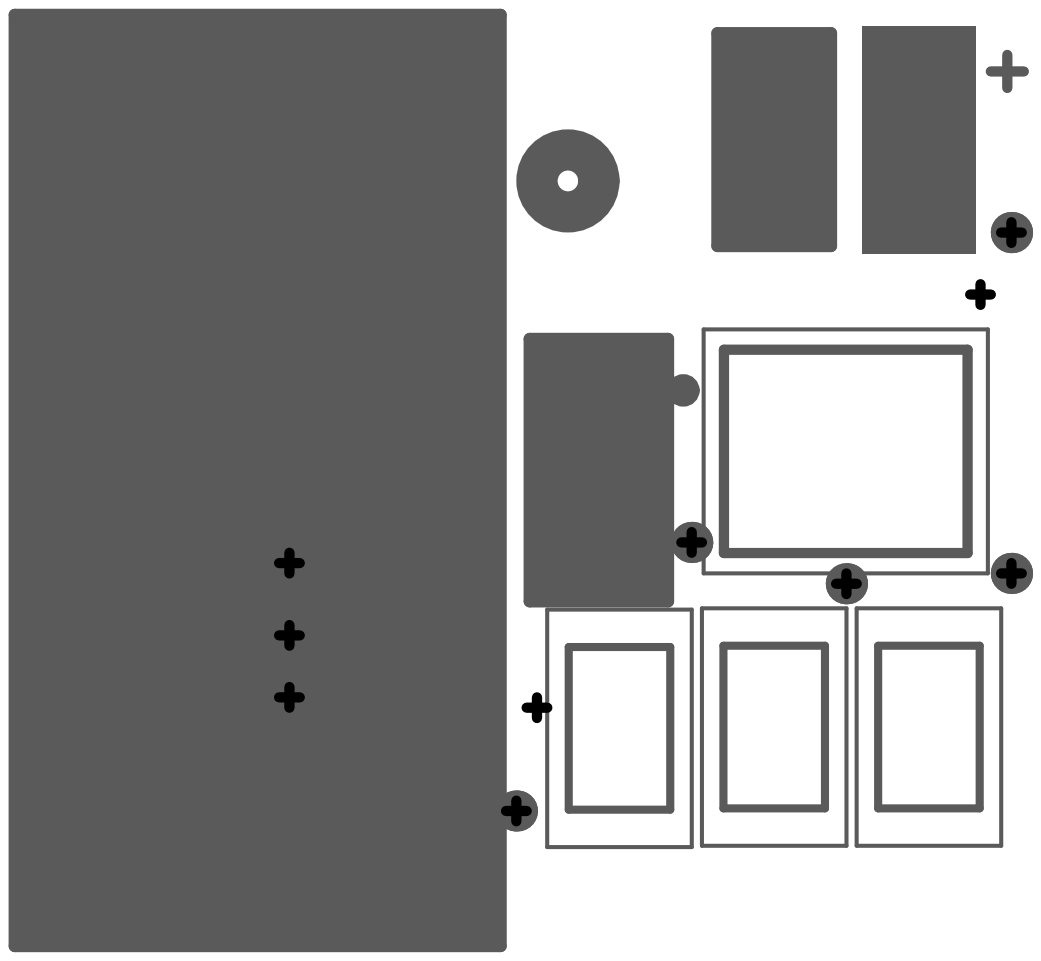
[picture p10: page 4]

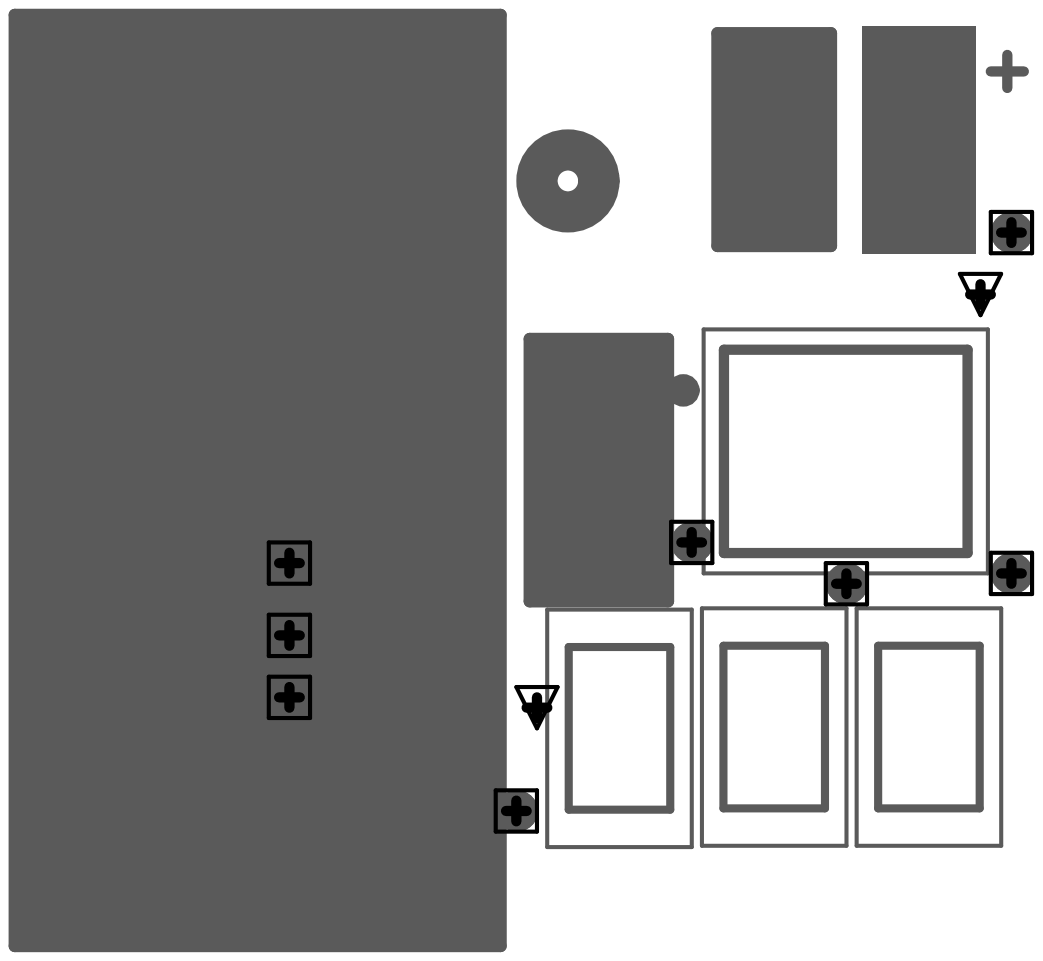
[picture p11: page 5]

Layer | Board Layer Stack | Name | Material | Thickness | Constant
1 | | Top Overlay | | 0mil
2 | | Top Solder | Solder Resist | 0.4mil | 3.5
3 | | Top Layer | | 1.4mil
4 | | Dielectric 1 | FR-4 | 12.6mil | 4.8
5 | | Bottom Layer | | 1.4mil
6 | | Bottom Solder | Solder Resist | 0.4mil | 3.5
7 | | Bottom Overlay | | 0mil
| Height : 16.2mil

# Board Stack Report

Stack Up | Layer Stack

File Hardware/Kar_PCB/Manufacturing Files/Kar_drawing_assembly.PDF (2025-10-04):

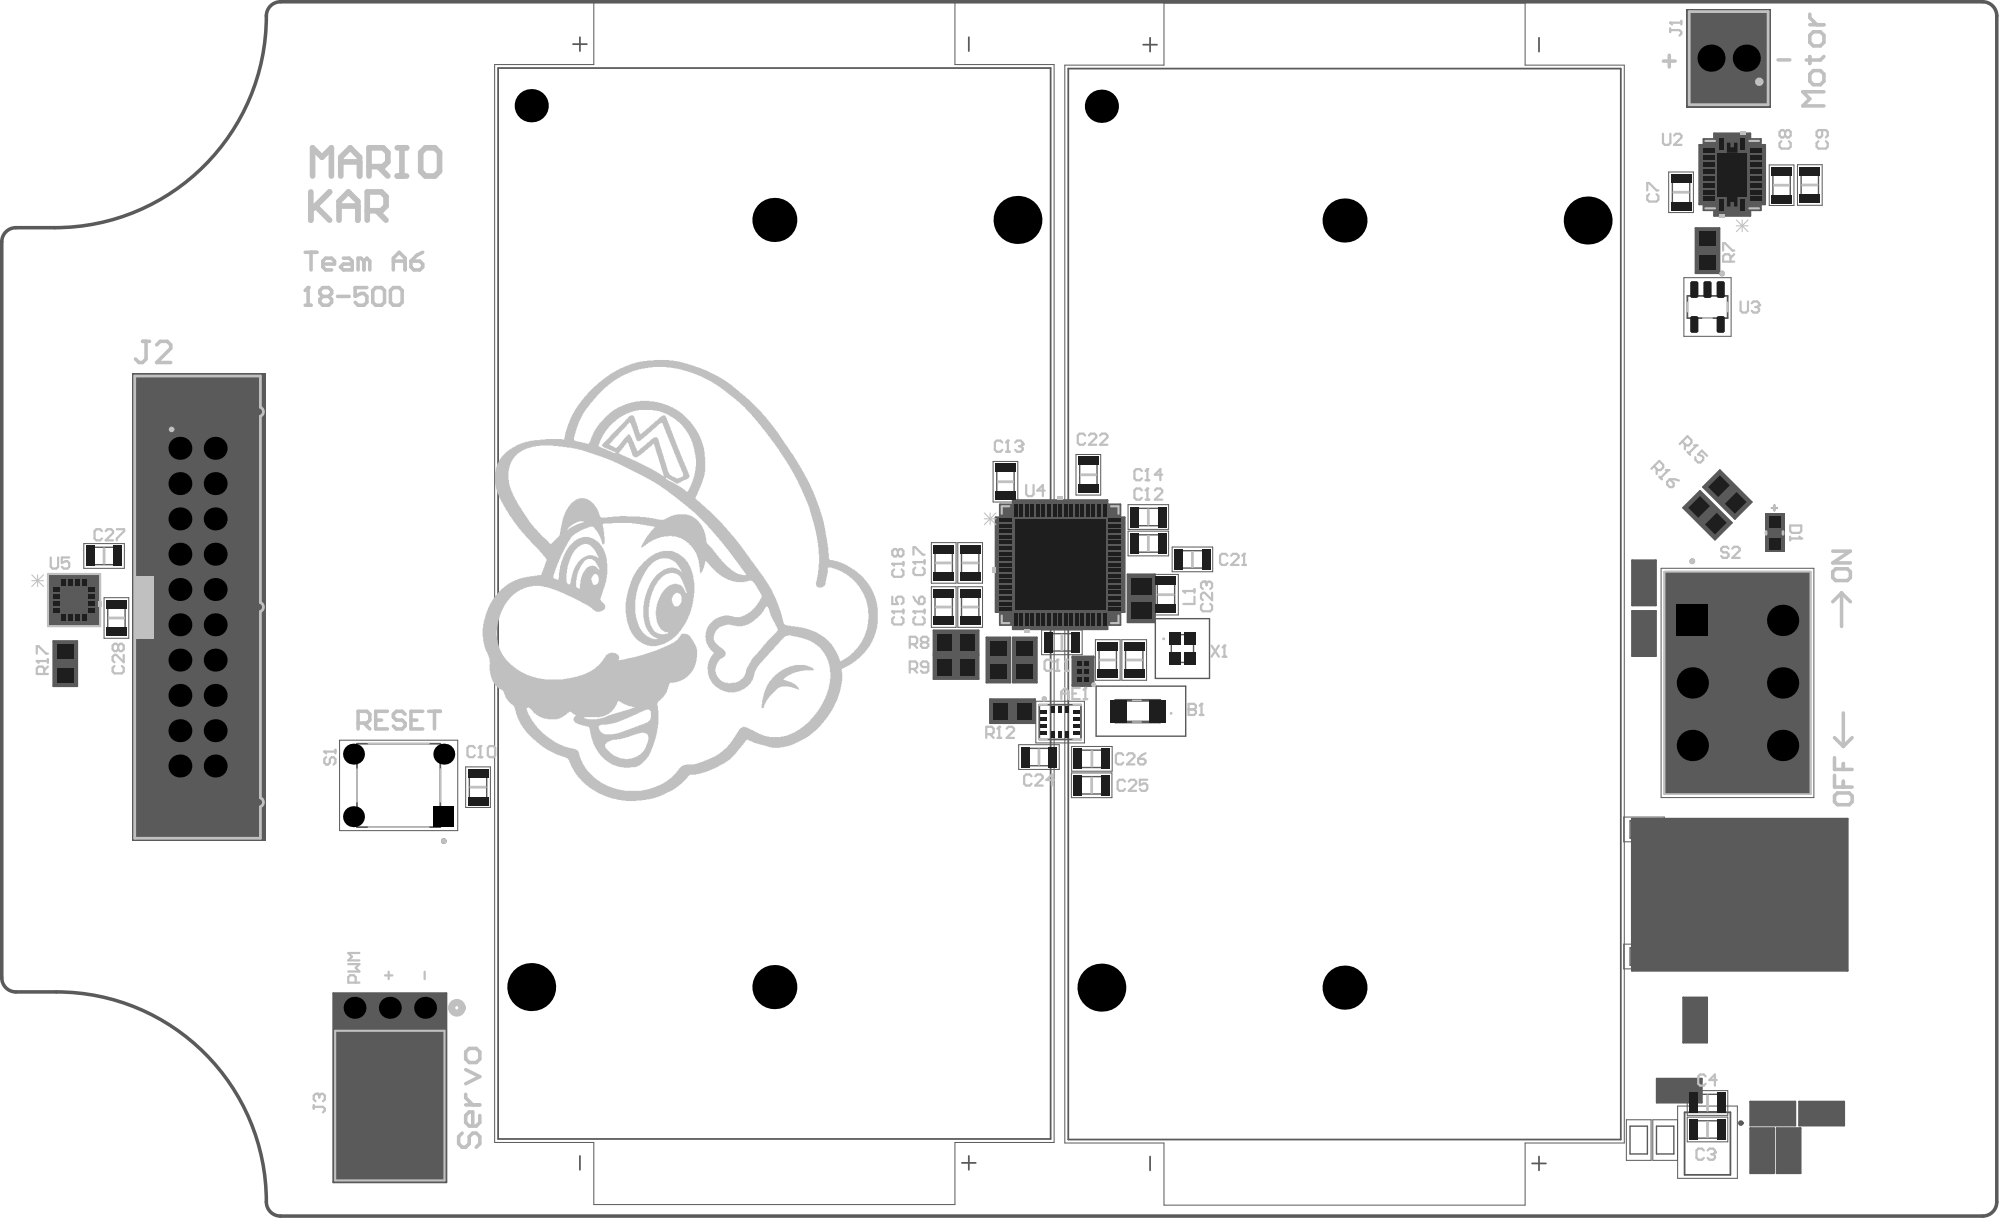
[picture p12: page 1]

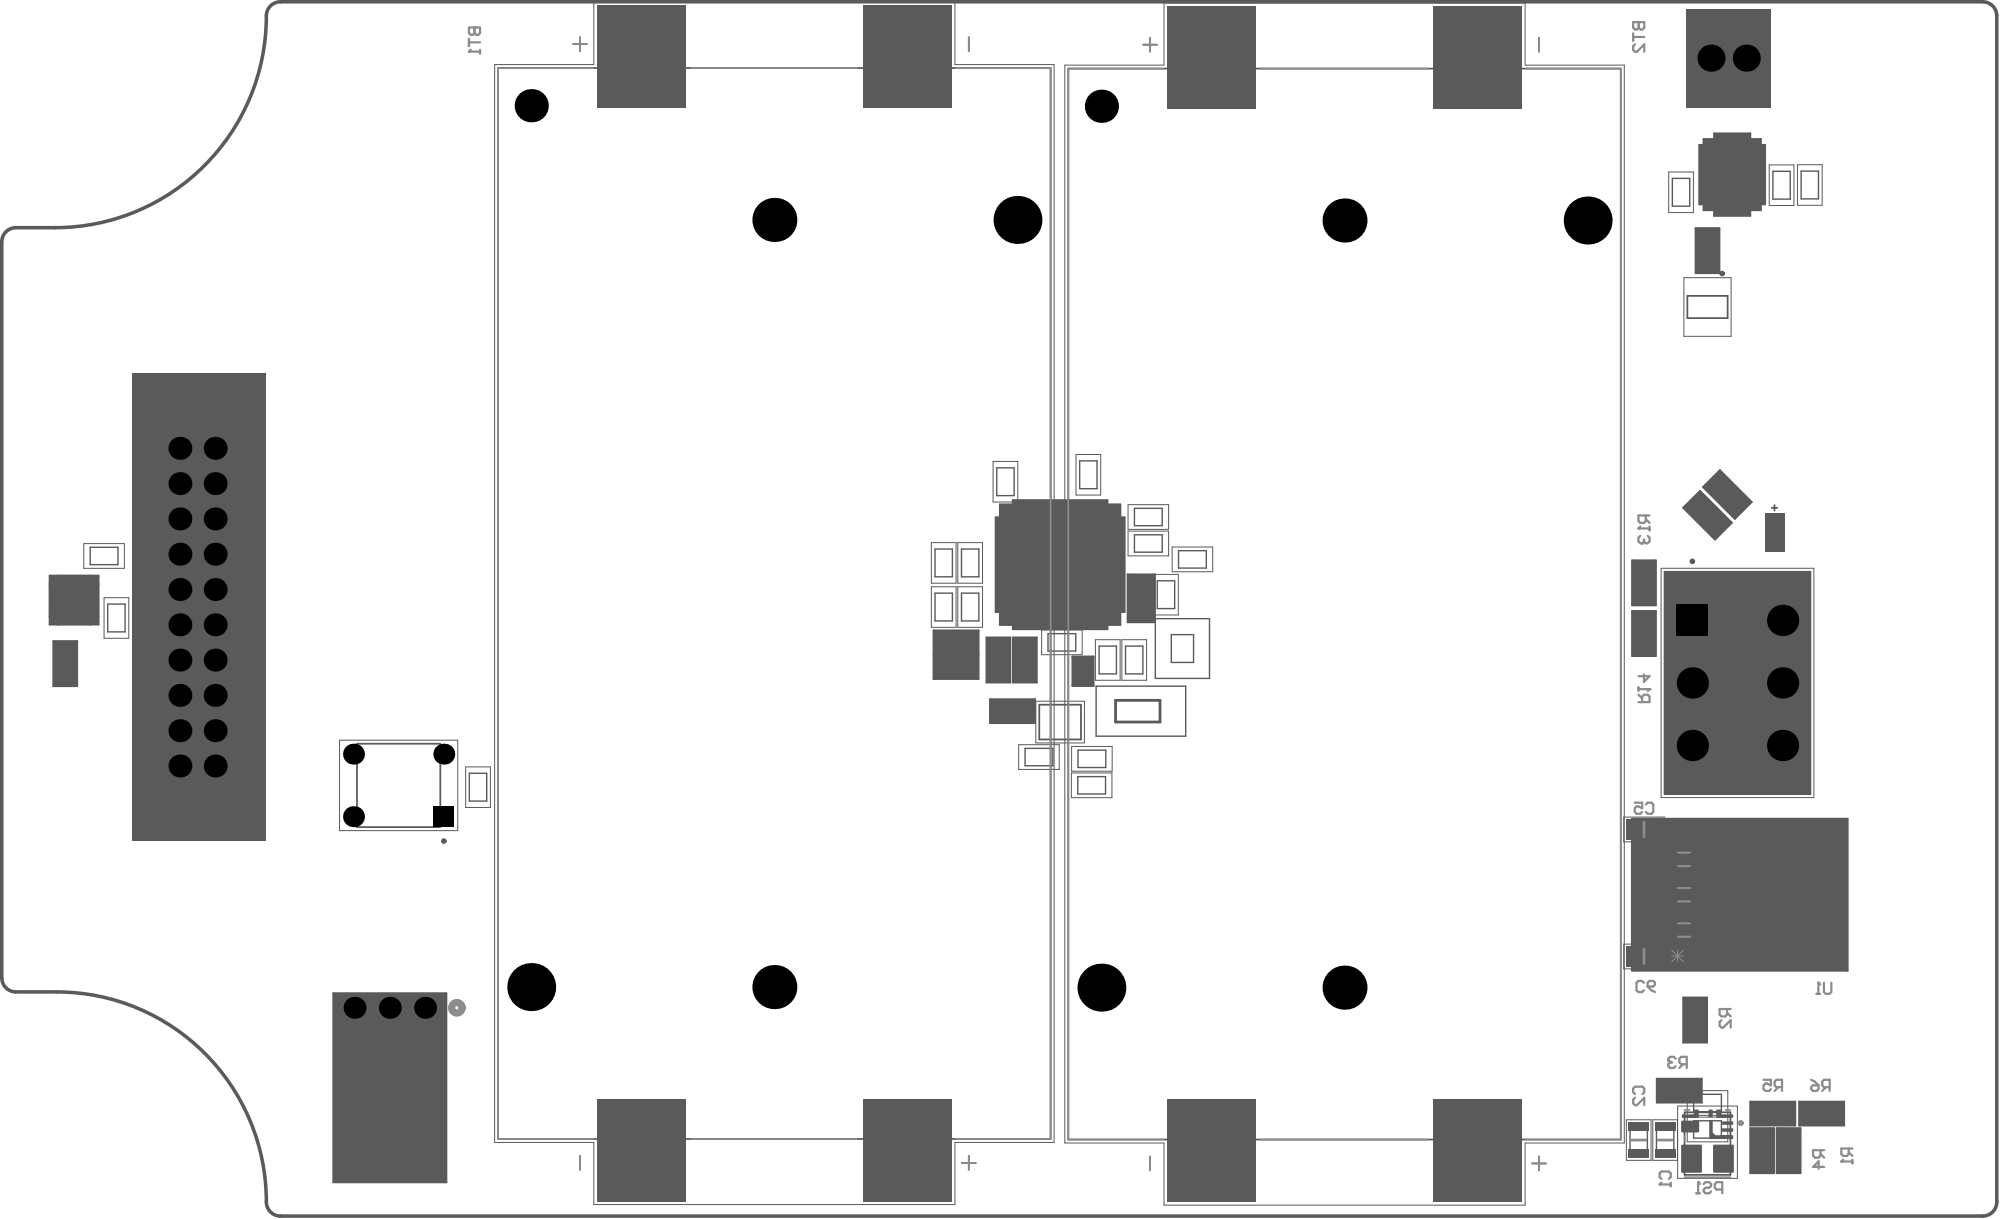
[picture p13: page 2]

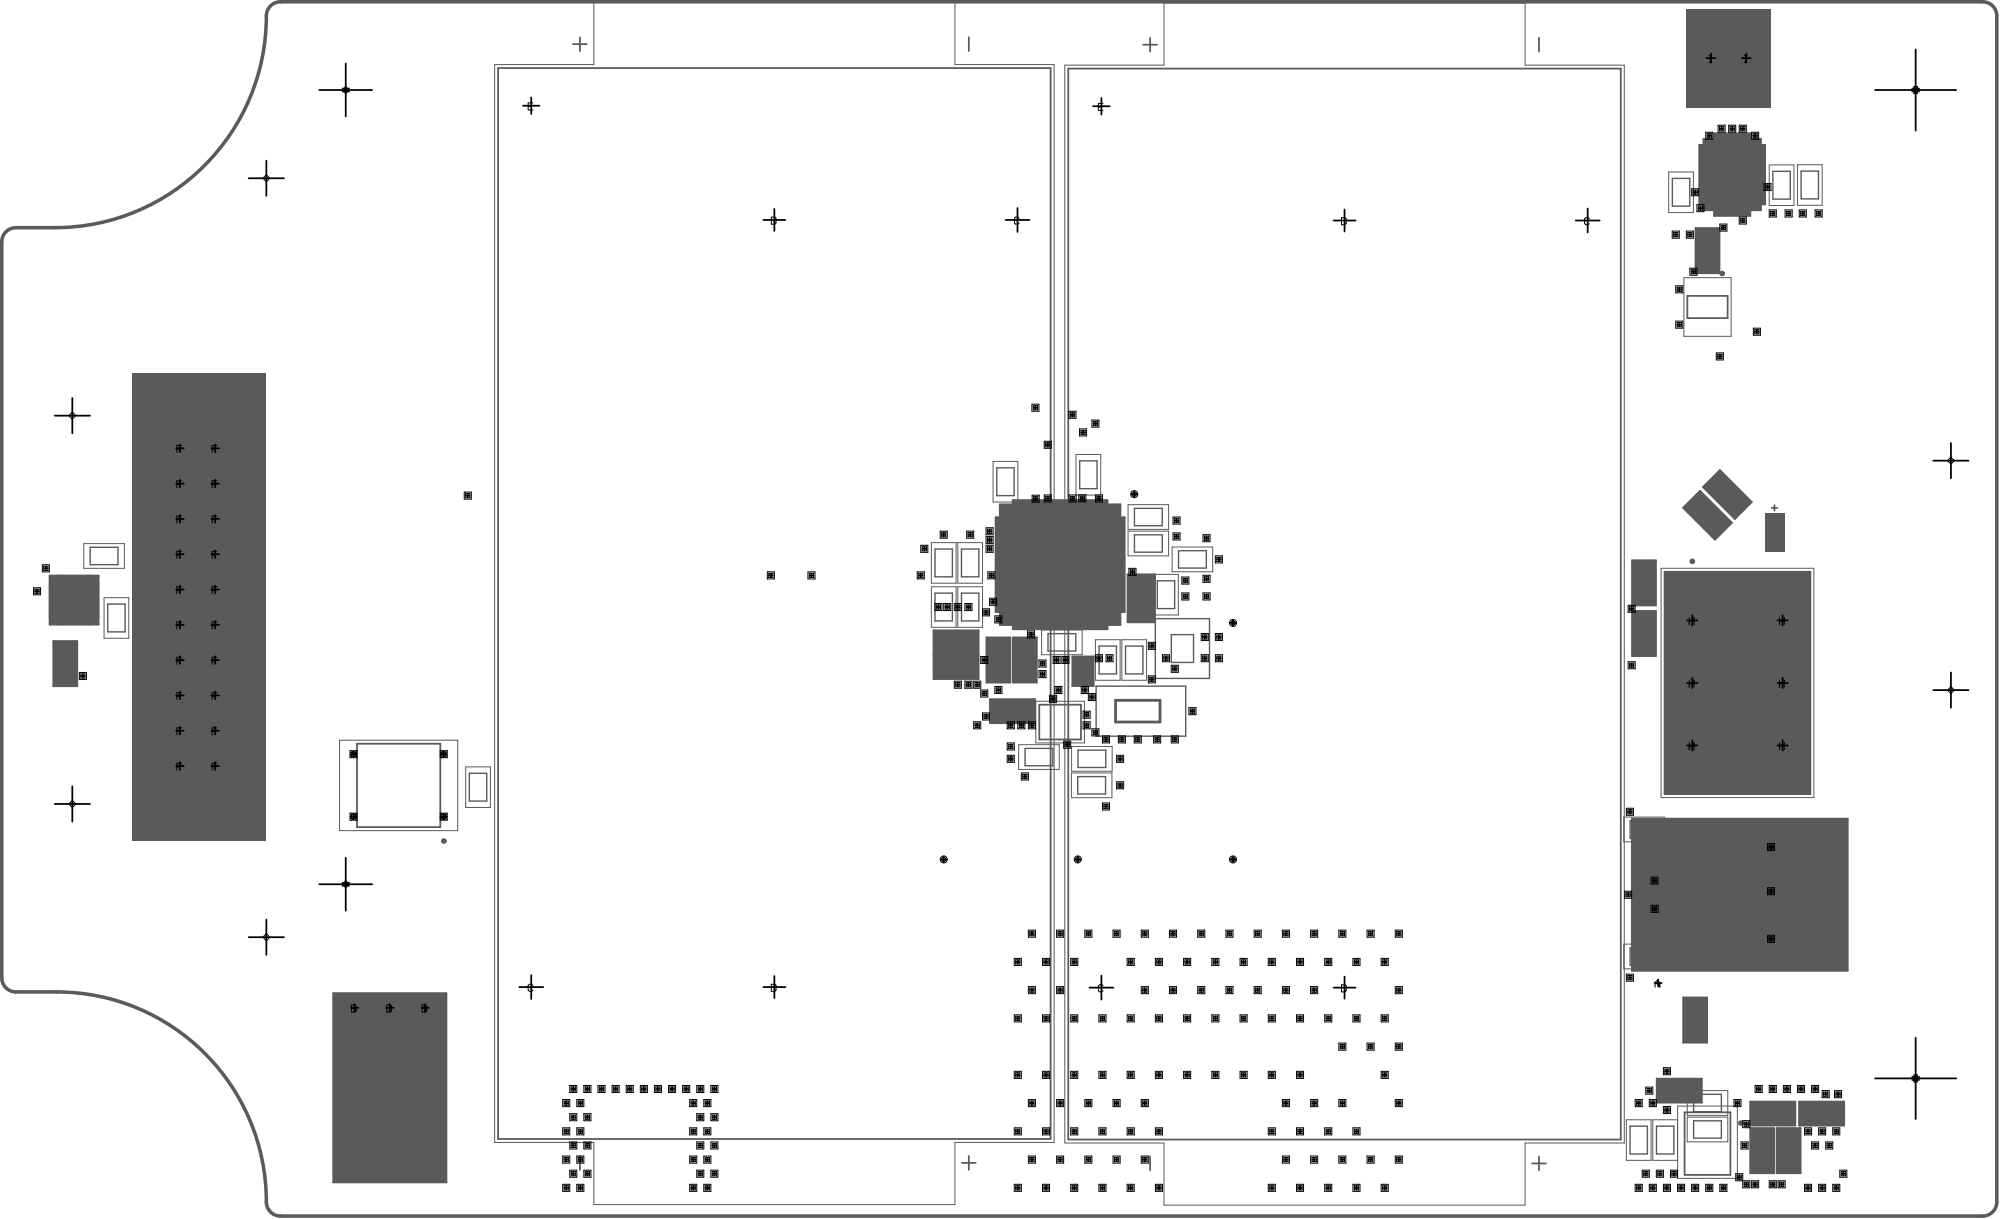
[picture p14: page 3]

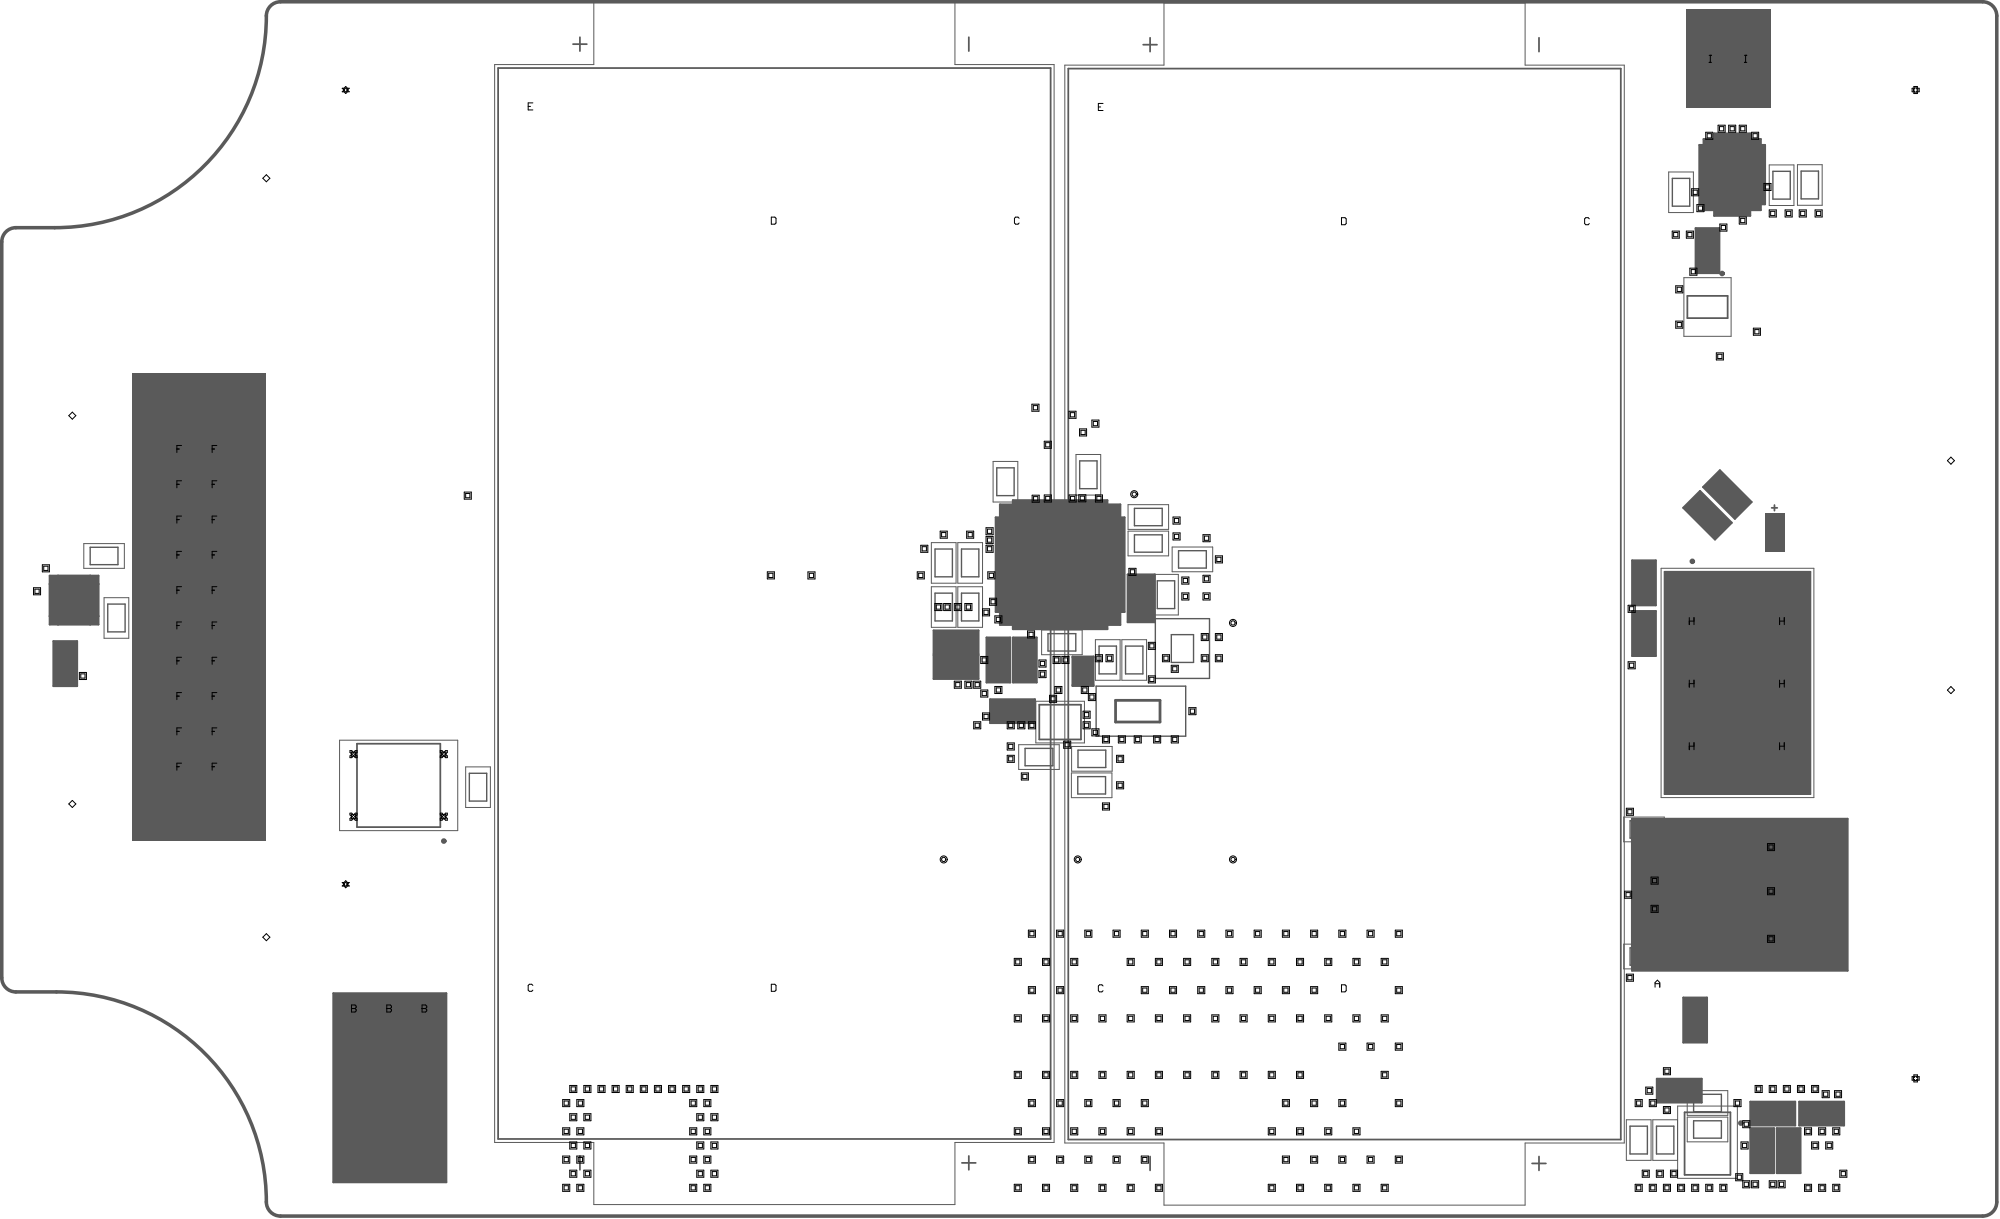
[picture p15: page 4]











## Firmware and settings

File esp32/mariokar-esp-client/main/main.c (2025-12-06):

/*
 * GATT Client for STM32WB P2P Server (ESP-IDF)
 * Legacy GAP scanning (set_scan_params / start_scanning / stop_scanning)
 * Features:
 *  - Connect to "MyCST"
 *  - Discover service by 128-bit UUID
 *  - Find LED (write) and SWITCH (notify) characteristics
 *  - Enable notifications
 *  - Send LED ON command after CCCD is enabled
 */

#include <stdio.h>
#include <string.h>
#include <stdlib.h>  // malloc/free
#include <math.h>    // logf
#include "freertos/FreeRTOS.h"
#include "freertos/task.h"
#include "nvs_flash.h"
#include "esp_bt.h"
#include "esp_bt_main.h"
#include "esp_gap_ble_api.h"
#include "esp_gattc_api.h"
#include "esp_gatt_common_api.h"
#include "nvs.h"
#include "esp_log.h"
#include "esp_timer.h"
#include "driver/usb_serial_jtag.h"
#include "driver/gpio.h"
#include "sensor.h"
#include "drv2605l.h"
#include "driver/i2c.h"

#define I2C_MASTER_SCL_IO    GPIO_NUM_6    // Xiao ESP32S3 default SCL
#define I2C_MASTER_SDA_IO    GPIO_NUM_5    // Xiao ESP32S3 default SDA
#define I2C_MASTER_NUM       I2C_NUM_0
#define I2C_MASTER_FREQ_HZ   400000

// GPIO configuration for reverse button
#define GPIO_REVERSE_BUTTON    GPIO_NUM_10
#define GPIO_INPUT_PIN_SEL     (1ULL << GPIO_REVERSE_BUTTON)

// GPIO configuration for CAL diode
#define GPIO_CAL_DIODE     GPIO_NUM_40
#define GPIO_INPUT_CAL_SEL (1ULL << GPIO_NUM_40)
    
#define GATTC_TAG "GATTC_CLEAN"
#define PROFILE_NUM        1
#define PROFILE_APP_ID     0
#define INVALID_HANDLE     0

// IMU → BLE TX settings
#define BLE_TX_INTERVAL_MS      50

static const char *TAG = "MAIN";

// Target device name advertised by STM32WB
static char remote_device_name[] = "MyCST";

static bool is_connected = false;
static bool service_found = false;

static esp_gattc_char_elem_t *char_elem_result   = NULL;
static esp_gattc_descr_elem_t *descr_elem_result = NULL;

// Latency test state
static uint16_t s_latency_seq = 0;
static int64_t  s_latency_t_send_us = 0;

/* STM32WB P2P 128-bit UUIDs (little endian for ESP) */
static esp_bt_uuid_t p2p_service_uuid = {
    .len = ESP_UUID_LEN_128,
    .uuid.uuid128 = {
        0x8f, 0xe5, 0xb3, 0xd5, 0x2e, 0x7f, 0x4a, 0x98,
        0x2a, 0x48, 0x7a, 0xcc, 0x40, 0xfe, 0x00, 0x00
    }
};

static esp_bt_uuid_t led_char_uuid = {
    .len = ESP_UUID_LEN_128,
    .uuid.uuid128 = {
        0x19, 0xed, 0x82, 0xae, 0xed, 0x21, 0x4c, 0x9d,
        0x41, 0x45, 0x22, 0x8e, 0x41, 0xfe, 0x00, 0x00
    }
};

static esp_bt_uuid_t switch_char_uuid = {
    .len = ESP_UUID_LEN_128,
    .uuid.uuid128 = {
        0x19, 0xed, 0x82, 0xae, 0xed, 0x21, 0x4c, 0x9d,
        0x41, 0x45, 0x22, 0x8e, 0x42, 0xfe, 0x00, 0x00
    }
};

static esp_bt_uuid_t notify_descr_uuid = {
    .len = ESP_UUID_LEN_16,
    .uuid = {.uuid16 = ESP_GATT_UUID_CHAR_CLIENT_CONFIG}
};

static esp_ble_scan_params_t ble_scan_params = {
    .scan_type = BLE_SCAN_TYPE_ACTIVE,
    .own_addr_type = BLE_ADDR_TYPE_PUBLIC,
    .scan_filter_policy = BLE_SCAN_FILTER_ALLOW_ALL,
    .scan_interval = 0x50,
    .scan_window = 0x30,
    .scan_duplicate = BLE_SCAN_DUPLICATE_DISABLE
};

struct gattc_profile_inst {
    esp_gattc_cb_t gattc_cb;
    uint16_t gattc_if;
    uint16_t app_id;
    uint16_t conn_id;
    uint16_t service_start_handle;
    uint16_t service_end_handle;
    uint16_t led_handle;     // VALUE handle we will write to
    uint16_t switch_handle;  // DECLARATION handle (used to find CCCD)
    esp_bd_addr_t remote_bda;
};

static struct gattc_profile_inst gl_profile_tab[PROFILE_NUM] = {
    [PROFILE_APP_ID] = { .gattc_if = ESP_GATT_IF_NONE },
};

static bool uuid_equal(const esp_bt_uuid_t *a, const esp_bt_uuid_t *b) {
    if (a->len != b->len) { return false; }
    switch (a->len) {
        case ESP_UUID_LEN_16:  return a->uuid.uuid16 == b->uuid.uuid16;
        case ESP_UUID_LEN_32:  return a->uuid.uuid32 == b->uuid.uuid32;
        case ESP_UUID_LEN_128: return memcmp(a->uuid.uuid128, b->uuid.uuid128, ESP_UUID_LEN_128) == 0;
        default: return false;
    }
}

/* GAP callback */
static void esp_gap_cb(esp_gap_ble_cb_event_t event, esp_ble_gap_cb_param_t *param) {
    switch (event) {
    case ESP_GAP_BLE_SCAN_PARAM_SET_COMPLETE_EVT:
        esp_ble_gap_start_scanning(30);
        break;

    case ESP_GAP_BLE_SCAN_RESULT_EVT: {
        esp_ble_gap_cb_param_t *scan_result = param;
        if (scan_result->scan_rst.search_evt == ESP_GAP_SEARCH_INQ_RES_EVT) {
            uint8_t adv_name_len = 0;

            uint8_t *adv_name = esp_ble_resolve_adv_data(
                scan_result->scan_rst.ble_adv,
                ESP_BLE_AD_TYPE_NAME_CMPL,
                &adv_name_len);

            if (adv_name && adv_name_len == strlen(remote_device_name) &&
                strncmp((char *)adv_name, remote_device_name, adv_name_len) == 0) {

                ESP_LOGI(GATTC_TAG, "Found target device %s", remote_device_name);
                esp_ble_gap_stop_scanning();

                esp_ble_gatt_creat_conn_params_t params = {0};
                memcpy(params.remote_bda, scan_result->scan_rst.bda, ESP_BD_ADDR_LEN);
                params.remote_addr_type = scan_result->scan_rst.ble_addr_type;
                params.own_addr_type = BLE_ADDR_TYPE_PUBLIC;
                params.is_direct = true;

                esp_err_t err = esp_ble_gattc_enh_open(gl_profile_tab[PROFILE_APP_ID].gattc_if, &params);
                if (err != ESP_OK) {
                    ESP_LOGE(GATTC_TAG, "enh_open failed: %s", esp_err_to_name(err));
                }
            }
        }
        break;
    }

    default:
        break;
    }
}

/* GATTC events */
static void gattc_profile_event_handler(esp_gattc_cb_event_t event,
                                        esp_gatt_if_t gattc_if,
                                        esp_ble_gattc_cb_param_t *param) {
    switch (event) {
    case ESP_GATTC_REG_EVT:
        esp_ble_gap_set_scan_params(&ble_scan_params);
        break;

    case ESP_GATTC_CONNECT_EVT: {
        is_connected = true;
        gl_profile_tab[PROFILE_APP_ID].conn_id = param->connect.conn_id;
        memcpy(gl_profile_tab[PROFILE_APP_ID].remote_bda, param->connect.remote_bda, ESP_BD_ADDR_LEN);

        // Clean cache to avoid stale handles while iterating
        esp_err_t e = esp_ble_gattc_cache_clean(gl_profile_tab[PROFILE_APP_ID].remote_bda);
        ESP_LOGI(GATTC_TAG, "gattc_cache_clean: %s", esp_err_to_name(e));

        esp_ble_gattc_send_mtu_req(gattc_if, param->connect.conn_id);

        // Request specific supervision timeout (6000 ms) while keeping a reasonable interval
        // Note: units are 1.25 ms for interval and 10 ms for timeout
        esp_ble_conn_update_params_t conn_params = {0};
        memcpy(conn_params.bda, param->connect.remote_bda, ESP_BD_ADDR_LEN);
        conn_params.min_int = 20;    // 25 ms
        conn_params.max_int = 20;    // 25 ms
        conn_params.latency = 0;     // no slave latency
        conn_params.timeout = 100;   // 1000 ms supervision timeout
        esp_err_t uerr = esp_ble_gap_update_conn_params(&conn_params);
        ESP_LOGI(GATTC_TAG, "conn param update req: %s (min=%u max=%u lat=%u timeout=%u)",
                 esp_err_to_name(uerr),
                 conn_params.min_int, conn_params.max_int,
                 conn_params.latency, conn_params.timeout);
        break;
    }

    case ESP_GATTC_DIS_SRVC_CMPL_EVT:
        esp_ble_gattc_search_service(gattc_if, param->dis_srvc_cmpl.conn_id, &p2p_service_uuid);
        break;

    case ESP_GATTC_SEARCH_RES_EVT:
        if (uuid_equal(&param->search_res.srvc_id.uuid, &p2p_service_uuid)) {
            service_found = true;
            gl_profile_tab[PROFILE_APP_ID].service_start_handle = param->search_res.start_handle;
            gl_profile_tab[PROFILE_APP_ID].service_end_handle   = param->search_res.end_handle;
            ESP_LOGI(GATTC_TAG, "P2P Service found: start=0x%04x end=0x%04x",
                     gl_profile_tab[PROFILE_APP_ID].service_start_handle,
                     gl_profile_tab[PROFILE_APP_ID].service_end_handle);
        }
        break;

    case ESP_GATTC_SEARCH_CMPL_EVT: {
        if (!service_found) {
            ESP_LOGW(GATTC_TAG, "Service not found — skipping characteristic discovery");
            return;
        }

        // Get capacity (IN) for our characteristics buffer
        uint16_t capacity = 0;
        esp_err_t err = esp_ble_gattc_get_attr_count(gattc_if, param->search_cmpl.conn_id,
                                                    ESP_GATT_DB_CHARACTERISTIC,
                                                    gl_profile_tab[PROFILE_APP_ID].service_start_handle,
                                                    gl_profile_tab[PROFILE_APP_ID].service_end_handle,
                                                    INVALID_HANDLE, &capacity);
        if (err != ESP_OK || capacity == 0) {
            ESP_LOGE(GATTC_TAG, "Failed to get characteristic count (err=%s, count=%d)",
                     esp_err_to_name(err), capacity);
            return;
        }

        char_elem_result = malloc(sizeof(esp_gattc_char_elem_t) * capacity);
        if (!char_elem_result) {
            ESP_LOGE(GATTC_TAG, "Malloc failed for char_elem_result");
            return;
        }

        // ---------- LED Characteristic (Write) ----------
        uint16_t found = capacity;  // IMPORTANT: pass capacity IN
        err = esp_ble_gattc_get_char_by_uuid(gattc_if,
                                            param->search_cmpl.conn_id,
                                            gl_profile_tab[PROFILE_APP_ID].service_start_handle,
                                            gl_profile_tab[PROFILE_APP_ID].service_end_handle,
                                            led_char_uuid,
                                            char_elem_result,
                                            &found);
        if (err == ESP_OK && found > 0) {
            // STM32WB: value handle = declaration handle + 1
            gl_profile_tab[PROFILE_APP_ID].led_handle = char_elem_result[0].char_handle;
            ESP_LOGI(GATTC_TAG, "LED value handle 0x%04x", gl_profile_tab[PROFILE_APP_ID].led_handle);
        } else {
            ESP_LOGE(GATTC_TAG, "LED characteristic not found (err=%s, found=%d)",
                     esp_err_to_name(err), found);
        }

        // ---------- SWITCH Characteristic (Notify) ----------
        found = capacity;  // reset capacity for second query
        err = esp_ble_gattc_get_char_by_uuid(gattc_if,
                                            param->search_cmpl.conn_id,
                                            gl_profile_tab[PROFILE_APP_ID].service_start_handle,
                                            gl_profile_tab[PROFILE_APP_ID].service_end_handle,
                                            switch_char_uuid,
                                            char_elem_result,
                                            &found);
        if (err == ESP_OK && found > 0) {
            gl_profile_tab[PROFILE_APP_ID].switch_handle = char_elem_result[0].char_handle; // decl handle
            ESP_LOGI(GATTC_TAG, "SWITCH decl handle 0x%04x", gl_profile_tab[PROFILE_APP_ID].switch_handle);

            err = esp_ble_gattc_register_for_notify(gattc_if,
                                                    gl_profile_tab[PROFILE_APP_ID].remote_bda,
                                                    gl_profile_tab[PROFILE_APP_ID].switch_handle);
            if (err != ESP_OK) {
                ESP_LOGE(GATTC_TAG, "Failed to register for notifications (err=%s)",
                         esp_err_to_name(err));
            }
        } else {
            ESP_LOGW(GATTC_TAG, "SWITCH characteristic not found (err=%s, found=%d)",
                     esp_err_to_name(err), found);
        }

        free(char_elem_result);
        char_elem_result = NULL;
        break;
    }

    case ESP_GATTC_REG_FOR_NOTIFY_EVT: {
        // Find CCCD and enable notifications for SWITCH
        uint16_t capacity = 0;
        esp_err_t err = esp_ble_gattc_get_attr_count(gattc_if,
                                                    gl_profile_tab[PROFILE_APP_ID].conn_id,
                                                    ESP_GATT_DB_DESCRIPTOR,
                                                    gl_profile_tab[PROFILE_APP_ID].service_start_handle,
                                                    gl_profile_tab[PROFILE_APP_ID].service_end_handle,
                                                    gl_profile_tab[PROFILE_APP_ID].switch_handle,
                                                    &capacity);
        if (err != ESP_OK || capacity == 0) {
            ESP_LOGE(GATTC_TAG, "No CCCD descriptor found (err=%s, count=%d)",
                     esp_err_to_name(err), capacity);
            break;
        }

        descr_elem_result = malloc(sizeof(esp_gattc_descr_elem_t) * capacity);
        if (!descr_elem_result) {
            ESP_LOGE(GATTC_TAG, "Malloc failed for descr_elem_result");
            break;
        }

        uint16_t found = capacity; // IN = capacity
        err = esp_ble_gattc_get_descr_by_char_handle(gattc_if,
                                                    gl_profile_tab[PROFILE_APP_ID].conn_id,
                                                    gl_profile_tab[PROFILE_APP_ID].switch_handle,
                                                    notify_descr_uuid,
                                                    descr_elem_result,
                                                    &found);
        if (err != ESP_OK || found == 0) {
            ESP_LOGE(GATTC_TAG, "Failed to get descriptor handle (err=%s, found=%d)",
                     esp_err_to_name(err), found);
            free(descr_elem_result);
            break;
        }

        uint16_t notify_en = 1;
        err = esp_ble_gattc_write_char_descr(gattc_if,
                                            gl_profile_tab[PROFILE_APP_ID].conn_id,
                                            descr_elem_result[0].handle,
                                            sizeof(notify_en),
                                            (uint8_t *)&notify_en,
                                            ESP_GATT_WRITE_TYPE_RSP,
                                            ESP_GATT_AUTH_REQ_NONE);
        if (err != ESP_OK) {
            ESP_LOGE(GATTC_TAG, "Failed to write CCCD (err=%s)", esp_err_to_name(err));
        } else {
            ESP_LOGI(GATTC_TAG, "CCCD write request sent to handle=0x%04x",
                     descr_elem_result[0].handle);
        }

        free(descr_elem_result);
        descr_elem_result = NULL;
        break;
    }

    case ESP_GATTC_WRITE_DESCR_EVT:
        ESP_LOGI(GATTC_TAG, "Notifications enabled.");
        break;

    case ESP_GATTC_NOTIFY_EVT: {
        const uint8_t *v = param->notify.value;
        uint16_t len = param->notify.value_len;

        // Latency test response: 2-byte seq echoed from STM32
        if (len == 2) {
            uint16_t seq = (uint16_t)v[0] | ((uint16_t)v[1] << 8);
            int64_t t_recv_us = esp_timer_get_time();
            double rtt_ms = (double)(t_recv_us - s_latency_t_send_us) / 1000.0;

            ESP_LOGI(GATTC_TAG,
                     "Latency test: seq=%u, RTT=%.3f ms",
                     seq, rtt_ms);
        } else {
            // Fallback: dump any other notifications (if you later send more data on SWITCH_C)
            ESP_LOGI(GATTC_TAG, "SWITCH Notification (%d bytes):", len);
            ESP_LOG_BUFFER_HEX(GATTC_TAG, v, len);
        }
        break;
    }

    case ESP_GATTC_DISCONNECT_EVT:
        ESP_LOGI(GATTC_TAG, "Disconnected");
        is_connected = false;
        service_found = false;
        gl_profile_tab[PROFILE_APP_ID].led_handle = INVALID_HANDLE;
        gl_profile_tab[PROFILE_APP_ID].switch_handle = INVALID_HANDLE;

        // Automatically restart scanning so we can reconnect to the STM32
        // 0 = scan indefinitely until we find "MyCST" again
        {
            esp_err_t err = esp_ble_gap_start_scanning(0);
            if (err != ESP_OK) {
                ESP_LOGE(GATTC_TAG, "Failed to restart scanning after disconnect: %s",
                         esp_err_to_name(err));
            } else {
                ESP_LOGI(GATTC_TAG, "Restarted BLE scan after disconnect");
            }
        }
        break;

    case ESP_GATTC_CFG_MTU_EVT:
        ESP_LOGI(GATTC_TAG, "MTU configured to %d", param->cfg_mtu.mtu);
        esp_ble_gattc_search_service(gattc_if, param->cfg_mtu.conn_id, &p2p_service_uuid);
        break;

    default:
        break;
    }
}

/* Dispatcher */
static void esp_gattc_cb(esp_gattc_cb_event_t event, esp_gatt_if_t gattc_if,
                         esp_ble_gattc_cb_param_t *param) {
    if (event == ESP_GATTC_REG_EVT)
        gl_profile_tab[param->reg.app_id].gattc_if = gattc_if;

    if (gattc_if == ESP_GATT_IF_NONE ||
        gattc_if == gl_profile_tab[PROFILE_APP_ID].gattc_if)
        gattc_profile_event_handler(event, gattc_if, param);
}

// Shared state between dual IMU readers and BLE TX
typedef struct {
    uint16_t icm_roll;   // ICM-20948 roll PWM (1500-1650 µs, inverted: 0°=1650, 90°=1500)
    uint16_t icm_pitch;  // ICM-20948 pitch PWM (1500-1650 µs, inverted: 0°=1650, 90°=1500)
    uint16_t mpu_roll;   // MPU-6050 roll PWM (1000-2000 µs range)
    uint16_t mpu_pitch;  // MPU-6050 pitch PWM (1000-2000 µs range)
} dual_imu_pwm_t;

static volatile uint8_t haptic_intensity;

static volatile dual_imu_pwm_t s_latest_pwm = {1580, 1580, 1500, 1500}; // ICM center=1650 (0°), MPU center=1500
static volatile bool s_icm_ready = false;
static volatile bool s_mpu_ready = false;

// Reverse flag controlled by GPIO button
static volatile bool s_reverse_mode = false;

static void send_latency_test(void)
{
    if (!is_connected ||
        gl_profile_tab[PROFILE_APP_ID].led_handle == INVALID_HANDLE ||
        gl_profile_tab[PROFILE_APP_ID].gattc_if == ESP_GATT_IF_NONE) {
        return;
    }

    uint8_t payload[3];
    s_latency_seq++;

    payload[0] = 0xFF;
    payload[1] = (uint8_t)(s_latency_seq & 0xFF);
    payload[2] = (uint8_t)(s_latency_seq >> 8);

    s_latency_t_send_us = esp_timer_get_time();

    esp_err_t err = esp_ble_gattc_write_char(
        gl_profile_tab[PROFILE_APP_ID].gattc_if,
        gl_profile_tab[PROFILE_APP_ID].conn_id,
        gl_profile_tab[PROFILE_APP_ID].led_handle,
        sizeof(payload),
        payload,
        ESP_GATT_WRITE_TYPE_NO_RSP,
        ESP_GATT_AUTH_REQ_NONE
    );

    if (err != ESP_OK) {
        ESP_LOGW(GATTC_TAG, "Latency test write failed: %s", esp_err_to_name(err));
    } else {
        ESP_LOGI(GATTC_TAG, "Latency test sent, seq=%u", s_latency_seq);
    }
}

static void latency_test_task(void *arg)
{
    while (1) {
        if (is_connected) {
            send_latency_test();
        }
        vTaskDelay(pdMS_TO_TICKS(1000));   // one test per second
    }
}

/**
 * @brief Persist reverse flag to NVS
 */
static void reverse_state_save(bool value)
{
    nvs_handle_t nvs;
    esp_err_t err = nvs_open("app", NVS_READWRITE, &nvs);
    if (err == ESP_OK) {
        uint8_t v = value ? 1 : 0;
        nvs_set_u8(nvs, "reverse", v);
        nvs_commit(nvs);
        nvs_close(nvs);
        ESP_LOGI(GATTC_TAG, "Reverse state saved: %s", value ? "ON" : "OFF");
    } else {
        ESP_LOGW(GATTC_TAG, "NVS open failed for save: %s", esp_err_to_name(err));
    }
}

/**
 * @brief Load reverse flag from NVS (defaults to OFF if not present)
 */
static void reverse_state_load(void)
{
    nvs_handle_t nvs;
    esp_err_t err = nvs_open("app", NVS_READONLY, &nvs);
    if (err == ESP_OK) {
        uint8_t v = 0;
        err = nvs_get_u8(nvs, "reverse", &v);
        nvs_close(nvs);
        if (err == ESP_OK) {
            s_reverse_mode = (v != 0);
            ESP_LOGI(GATTC_TAG, "Reverse state loaded: %s", s_reverse_mode ? "ON" : "OFF");
        } else if (err == ESP_ERR_NVS_NOT_FOUND) {
            ESP_LOGI(GATTC_TAG, "Reverse state not found in NVS, defaulting to OFF");
            s_reverse_mode = false;
        } else {
            ESP_LOGW(GATTC_TAG, "NVS get failed: %s", esp_err_to_name(err));
        }
    } else {
        ESP_LOGW(GATTC_TAG, "NVS open failed for load: %s", esp_err_to_name(err));
    }
}
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
void app_main(void) {

    esp_err_t ret = nvs_flash_init();
    if (ret == ESP_ERR_NVS_NO_FREE_PAGES || ret == ESP_ERR_NVS_NEW_VERSION_FOUND) {
        nvs_flash_erase();
        nvs_flash_init();
    }

    // Load persisted reverse state
    reverse_state_load();

    // Initialize reverse button on GPIO1
    init_reverse_button();

    // init_CAL();

    // gpio_set_level(GPIO_CAL_DIODE, 1);

    i2c_init();

    // Start dual IMU reader tasks, BLE TX task, and reverse monitor
    xTaskCreate(icm20948_reader_task, "icm20948", 4096, NULL, 5, NULL);
    xTaskCreate(mpu6050_reader_task, "mpu6050", 4096, NULL, 5, NULL);
    xTaskCreate(haptic_task, "haptic", 4096, NULL, 3, NULL);
    xTaskCreate(ble_tx_task, "ble_tx", 3072, NULL, 6, NULL);
    xTaskCreate(reverse_monitor_task, "reverse_mon", 4096, NULL, 4, NULL);
    // xTaskCreate(latency_test_task, "lat_test", 3072, NULL, 4, NULL);

    esp_bt_controller_mem_release(ESP_BT_MODE_CLASSIC_BT);
    esp_bt_controller_config_t bt_cfg = BT_CONTROLLER_INIT_CONFIG_DEFAULT();
    esp_bt_controller_init(&bt_cfg);
    esp_bt_controller_enable(ESP_BT_MODE_BLE);
    esp_bluedroid_init();
    esp_bluedroid_enable();

    esp_ble_gap_register_callback(esp_gap_cb);
    esp_ble_gattc_register_callback(esp_gattc_cb);
    esp_ble_gattc_app_register(PROFILE_APP_ID);
    esp_ble_gatt_set_local_mtu(500);
}

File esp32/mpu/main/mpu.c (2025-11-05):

#include <stdio.h>
#include <math.h>
#include "freertos/FreeRTOS.h"
#include "freertos/task.h"
#include "driver/i2c.h"
#include "mpu6050.h"
#include "esp_log.h"

#define I2C_MASTER_SCL_IO    6
#define I2C_MASTER_SDA_IO    5
#define I2C_MASTER_NUM       I2C_NUM_0
#define I2C_MASTER_FREQ_HZ   400000

static const char *TAG = "MPU6050_MADGWICK";

// Madgwick filter structure
typedef struct {
    float q0, q1, q2, q3;  // Quaternion elements
    float beta;             // Filter gain
    float sample_freq;      // Sample frequency in Hz
} madgwick_t;

// Initialize Madgwick filter
void madgwick_init(madgwick_t *filter, float sample_freq, float beta) {
    filter->q0 = 1.0f;
    filter->q1 = 0.0f;
    filter->q2 = 0.0f;
    filter->q3 = 0.0f;
    filter->beta = beta;
    filter->sample_freq = sample_freq;
}

// Fast inverse square root
float inv_sqrt(float x) {
    float halfx = 0.5f * x;
    float y = x;
    long i = *(long*)&y;
    i = 0x5f3759df - (i>>1);
    y = *(float*)&i;
    y = y * (1.5f - (halfx * y * y));
    return y;
}

// Madgwick filter update (6DOF - accel + gyro only)
void madgwick_update(madgwick_t *filter, float gx, float gy, float gz, 
                     float ax, float ay, float az) {
    float recipNorm;
    float s0, s1, s2, s3;
    float qDot1, qDot2, qDot3, qDot4;
    float _2q0, _2q1, _2q2, _2q3, _4q0, _4q1, _4q2, _8q1, _8q2, q0q0, q1q1, q2q2, q3q3;

    // Convert gyroscope degrees/sec to radians/sec
    gx *= 0.0174533f;
    gy *= 0.0174533f;
    gz *= 0.0174533f;

    // Rate of change of quaternion from gyroscope
    qDot1 = 0.5f * (-filter->q1 * gx - filter->q2 * gy - filter->q3 * gz);
    qDot2 = 0.5f * (filter->q0 * gx + filter->q2 * gz - filter->q3 * gy);
    qDot3 = 0.5f * (filter->q0 * gy - filter->q1 * gz + filter->q3 * gx);
    qDot4 = 0.5f * (filter->q0 * gz + filter->q1 * gy - filter->q2 * gx);

    // Compute feedback only if accelerometer measurement valid (avoids NaN in accelerometer normalisation)
    if(!((ax == 0.0f) && (ay == 0.0f) && (az == 0.0f))) {

        // Normalise accelerometer measurement
        recipNorm = inv_sqrt(ax * ax + ay * ay + az * az);
        ax *= recipNorm;
        ay *= recipNorm;
        az *= recipNorm;

        // Auxiliary variables to avoid repeated arithmetic
        _2q0 = 2.0f * filter->q0;
        _2q1 = 2.0f * filter->q1;
        _2q2 = 2.0f * filter->q2;
        _2q3 = 2.0f * filter->q3;
        _4q0 = 4.0f * filter->q0;
        _4q1 = 4.0f * filter->q1;
        _4q2 = 4.0f * filter->q2;
        _8q1 = 8.0f * filter->q1;
        _8q2 = 8.0f * filter->q2;
        q0q0 = filter->q0 * filter->q0;
        q1q1 = filter->q1 * filter->q1;
        q2q2 = filter->q2 * filter->q2;
        q3q3 = filter->q3 * filter->q3;

        // Gradient decent algorithm corrective step
        s0 = _4q0 * q2q2 + _2q2 * ax + _4q0 * q1q1 - _2q1 * ay;
        s1 = _4q1 * q3q3 - _2q3 * ax + 4.0f * q0q0 * filter->q1 - _2q0 * ay - _4q1 + _8q1 * q1q1 + _8q1 * q2q2 + _4q1 * az;
        s2 = 4.0f * q0q0 * filter->q2 + _2q0 * ax + _4q2 * q3q3 - _2q3 * ay - _4q2 + _8q2 * q1q1 + _8q2 * q2q2 + _4q2 * az;
        s3 = 4.0f * q1q1 * filter->q3 - _2q1 * ax + 4.0f * q2q2 * filter->q3 - _2q2 * ay;
        recipNorm = inv_sqrt(s0 * s0 + s1 * s1 + s2 * s2 + s3 * s3);
        s0 *= recipNorm;
        s1 *= recipNorm;
        s2 *= recipNorm;
        s3 *= recipNorm;

        // Apply feedback step
        qDot1 -= filter->beta * s0;
        qDot2 -= filter->beta * s1;
        qDot3 -= filter->beta * s2;
        qDot4 -= filter->beta * s3;
    }

    // Integrate rate of change of quaternion to yield quaternion
    filter->q0 += qDot1 * (1.0f / filter->sample_freq);
    filter->q1 += qDot2 * (1.0f / filter->sample_freq);
    filter->q2 += qDot3 * (1.0f / filter->sample_freq);
    filter->q3 += qDot4 * (1.0f / filter->sample_freq);

    // Normalise quaternion
    recipNorm = inv_sqrt(filter->q0 * filter->q0 + filter->q1 * filter->q1 + filter->q2 * filter->q2 + filter->q3 * filter->q3);
    filter->q0 *= recipNorm;
    filter->q1 *= recipNorm;
    filter->q2 *= recipNorm;
    filter->q3 *= recipNorm;
}

// Convert quaternion to Euler angles (roll, pitch, yaw)
void madgwick_get_euler(madgwick_t *filter, float *roll, float *pitch, float *yaw) {
    // Roll (x-axis rotation)
    float sinr_cosp = 2.0f * (filter->q0 * filter->q1 + filter->q2 * filter->q3);
    float cosr_cosp = 1.0f - 2.0f * (filter->q1 * filter->q1 + filter->q2 * filter->q2);
    *roll = atan2f(sinr_cosp, cosr_cosp) * 57.2958f; // Convert to degrees

    // Pitch (y-axis rotation)
    float sinp = 2.0f * (filter->q0 * filter->q2 - filter->q3 * filter->q1);
    if (fabsf(sinp) >= 1.0f)
        *pitch = copysignf(90.0f, sinp); // Use 90 degrees if out of range
    else
        *pitch = asinf(sinp) * 57.2958f;

    // Yaw (z-axis rotation)
    float siny_cosp = 2.0f * (filter->q0 * filter->q3 + filter->q1 * filter->q2);
    float cosy_cosp = 1.0f - 2.0f * (filter->q2 * filter->q2 + filter->q3 * filter->q3);
    *yaw = atan2f(siny_cosp, cosy_cosp) * 57.2958f;
}
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

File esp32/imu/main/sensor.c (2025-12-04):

/**
 * @file sensor.c
 * @brief ICM-20948 9-axis IMU driver with SPI interface
 * 
 * Features:
 * - SPI communication with ICM-20948
 * - I2C master mode for AK09916 magnetometer
 * - Madgwick AHRS sensor fusion
 * - Gyroscope calibration
 */

#include "sensor.h"
#include "driver/spi_master.h"
#include "driver/gpio.h"
#include "esp_log.h"
#include "esp_timer.h"
#include "freertos/FreeRTOS.h"
#include "freertos/task.h"
#include <string.h>
#include <math.h>

static const char *TAG = "ICM20948";

// =============================================================================
// Hardware Configuration
// =============================================================================

// GPIO pin assignments for XIAO ESP32S3
#define PIN_MISO        GPIO_NUM_8
#define PIN_MOSI        GPIO_NUM_3
#define PIN_SCLK        GPIO_NUM_7
#define PIN_CS          GPIO_NUM_38

#define SPI_CLOCK_HZ    4000000  // 4 MHz SPI clock

// =============================================================================
// ICM-20948 Register Definitions
// =============================================================================

// Bank 0 Registers
#define REG_WHO_AM_I            0x00
#define REG_USER_CTRL           0x03
#define REG_PWR_MGMT_1          0x06
#define REG_PWR_MGMT_2          0x07
#define REG_INT_PIN_CFG         0x0F
#define REG_I2C_MST_STATUS      0x17
#define REG_ACCEL_XOUT_H        0x2D
#define REG_GYRO_XOUT_H         0x33
#define REG_EXT_SLV_SENS_DATA_00 0x3B
#define REG_BANK_SEL            0x7F

// Bank 2 Registers
#define REG_GYRO_SMPLRT_DIV     0x00
#define REG_GYRO_CONFIG_1       0x01
#define REG_GYRO_CONFIG_2       0x02
#define REG_ACCEL_SMPLRT_DIV_1  0x10
#define REG_ACCEL_SMPLRT_DIV_2  0x11
#define REG_ACCEL_CONFIG        0x14
#define REG_ACCEL_CONFIG_2      0x15

// Bank 3 Registers
#define REG_I2C_MST_CTRL        0x01
#define REG_I2C_SLV0_ADDR       0x03
#define REG_I2C_SLV0_REG        0x04
#define REG_I2C_SLV0_CTRL       0x05
#define REG_I2C_SLV0_DO         0x06

// Register Banks
#define BANK_0                  0x00
#define BANK_1                  0x10
#define BANK_2                  0x20
#define BANK_3                  0x30

// USER_CTRL bits
#define BIT_I2C_MST_EN          0x20
#define BIT_I2C_IF_DIS          0x10

// WHO_AM_I expected value
#define ICM20948_WHO_AM_I_VAL   0xEA

// =============================================================================
// AK09916 Magnetometer Definitions
// =============================================================================

#define AK09916_I2C_ADDR        0x0C
#define AK09916_WIA2            0x01
#define AK09916_ST1             0x10
#define AK09916_HXL             0x11
#define AK09916_ST2             0x18
#define AK09916_CNTL2           0x31
#define AK09916_CNTL3           0x32

#define AK09916_MODE_CONT_100HZ 0x08
#define AK09916_WIA2_VAL        0x09

// =============================================================================
// Sensor Configuration
// =============================================================================

#define GYRO_RANGE_DPS          500.0f
#define ACCEL_RANGE_G           4.0f
#define MAG_RANGE_UT            4912.0f

#define GYRO_SCALE              (GYRO_RANGE_DPS / 32768.0f)
#define ACCEL_SCALE             (ACCEL_RANGE_G / 32768.0f)
#define MAG_SCALE               (MAG_RANGE_UT / 32768.0f)

// =============================================================================
// Madgwick Filter Configuration
// =============================================================================

#define MADGWICK_BETA           0.1f
#define DEG_TO_RAD              (M_PI / 180.0f)
#define RAD_TO_DEG              (180.0f / M_PI)

// =============================================================================
// Static Variables
// =============================================================================

static spi_device_handle_t spi_handle = NULL;
static uint8_t current_bank = 0xFF;  // Track current register bank

// Gyroscope bias from calibration
static float gyro_bias[3] = {0.0f, 0.0f, 0.0f};

// Madgwick filter state (quaternion)
static float q0 = 1.0f, q1 = 0.0f, q2 = 0.0f, q3 = 0.0f;

// =============================================================================
// SPI Communication Functions
// =============================================================================

/**
 * @brief Select ICM-20948 register bank
 */
static esp_err_t select_bank(uint8_t bank)
{
    if (bank == current_bank) {
        return ESP_OK;  // Already in correct bank
    }

    uint8_t tx_data[2] = {REG_BANK_SEL & 0x7F, bank};
    spi_transaction_t trans = {
        .length = 16,
        .tx_buffer = tx_data,
    };

    esp_err_t ret = spi_device_polling_transmit(spi_handle, &trans);
    if (ret == ESP_OK) {
        current_bank = bank;
    }
    return ret;
}

/**
 * @brief Read single register from ICM-20948
 */
static esp_err_t read_register(uint8_t reg, uint8_t *data)
{
    uint8_t tx_data[2] = {reg | 0x80, 0x00};  // MSB=1 for read
    uint8_t rx_data[2] = {0};

    spi_transaction_t trans = {
        .length = 16,
        .tx_buffer = tx_data,
        .rx_buffer = rx_data,
    };

    esp_err_t ret = spi_device_polling_transmit(spi_handle, &trans);
    if (ret == ESP_OK) {
        *data = rx_data[1];
    }
    return ret;
}
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

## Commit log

2025-09-22 Altium project setup
    [MarioKarCB.PrjPcb, PCB1.PcbDoc, Sheet1.SchDoc]
2025-09-25 Kar PCB layout
    [Kar_PCB.SchDoc, MarioKarCB.PrjPcb, Motor.SchDoc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]
2025-09-26 99% Kar schematic
    [Kar_IMU.SchDoc, Kar_PCB.SchDoc, MarioKarCB.PrjPcb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]
2025-09-26 Glove schematic done
    [ADA_DRV2605L.PcbLib, ADA_DRV2605L.SchLib, ESP32.SchLib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]
2025-09-26 Minor schematic tweaks
    [Glove_PCB.SchDoc, Kar_IMU.SchDoc, Kar_PCB.SchDoc]
2025-09-26 SPI touchups + finger IMU
    [Finger_IMU_PCB.SchDoc, Glove_PCB.SchDoc, Kar_IMU.SchDoc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]
2025-09-27 Switched to real RLCs
    [Caps.SchLib, Finger_IMU_PCB.SchDoc, Glove_PCB.SchDoc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]
2025-09-27 Directory re-arrangement
    [Finger_IMU_PCB.SchDoc, Glove_PCB.SchDoc, Kar_IMU.SchDoc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]
2025-09-27 Glove layout progress
    [ADA_DRV2605L.PcbLib, ADA_DRV2605L.SchLib, Caps.SchLib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]
2025-09-28 Glove PCB layout done
    [Glove_PCB.PcbDoc, Glove_PCB.PrjPcb, Glove_PCB.SchDoc]
2025-09-28 Finger PCB layout done
    [Finger_IMU_PCB.PcbDoc, Finger_IMU_PCB.SchDoc, Finger_PCB.PrjPcb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]
2025-09-29 Kar PCB layout progress
    [Finger_IMU_PCB.SchDoc, Glove_PCB.PcbDoc, Glove_PCB.PrjPcb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]
2025-09-29 All boards DRC clean
    [Kar_PCB.PcbDoc, Kar_PCB.PrjPcb, Power.SchDoc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]
2025-10-04 Finishing tweaks
    [Bill of Materials-ActiveBOM.xlsx, Glove_PCB.PcbDoc, Glove_PCB.PrjPcb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]
2025-10-04 Quote gathering
    [Bill of Materials-ActiveBOM.xlsx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]
2025-10-04 Kart final touches
    [Kar_PCB.PcbDoc, Kar_PCB.PrjPcb, Kar_PCB.SchDoc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]
2025-10-04 Improved stitching vias
    [Kar_PCB.PcbDoc]
2025-10-04 Final edits for final quotes
    [ADA_DRV2605L.PcbLib, ADA_DRV2605L.SchLib, Bill of Materials-ActiveBOM.xlsx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]
2025-10-08 Kar rework for lower price
    [Bill of Materials-ActiveBOM.xlsx, Fiducial.PcbLib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]
2025-10-08 starting rtos framework, some broken imu and led task code, read me updates
    [imu.c, led.c, main.c]
2025-10-13 Finalized orders
    [Bill of Materials-ActiveBOM.xlsx, Caps.SchLib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]
2025-10-19 reading raw imu values
2025-10-19 fir filtering for imu
2025-11-01 new imu, very drifty
    [imu.c, main.c]
2025-11-03 Adding BLE + IMU ESP32 client code
2025-11-03 Add ESP32 projects, STM32 setup, and project structure
    - Add ESP32 IMU sensor project with BLE communication
    - Add ESP32 MarioKar client with sensor integration
    - Add STM32 development environment setup
    - Add hardware design files (Altium)
    - Add hello_world ESP32 example
    - Add .gitignore to exclude build artifacts
    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
2025-11-15 Working code for MPU->PWM and logarithmic mapping
2025-11-24 some possibly broken files
    [drv2605l.c, main.c, sensor_mpu6050.c]
2025-12-04 updated changes
    [rtt_results.csv]
2025-12-06 Adding safety/power-saving mechanisms to ESP32
